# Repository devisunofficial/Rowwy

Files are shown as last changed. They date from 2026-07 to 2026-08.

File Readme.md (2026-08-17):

# Rowwy
Rowwy is a hand-movement control car which uses Mecanum wheels.

### CAD Model:
It has two seperate bodies.

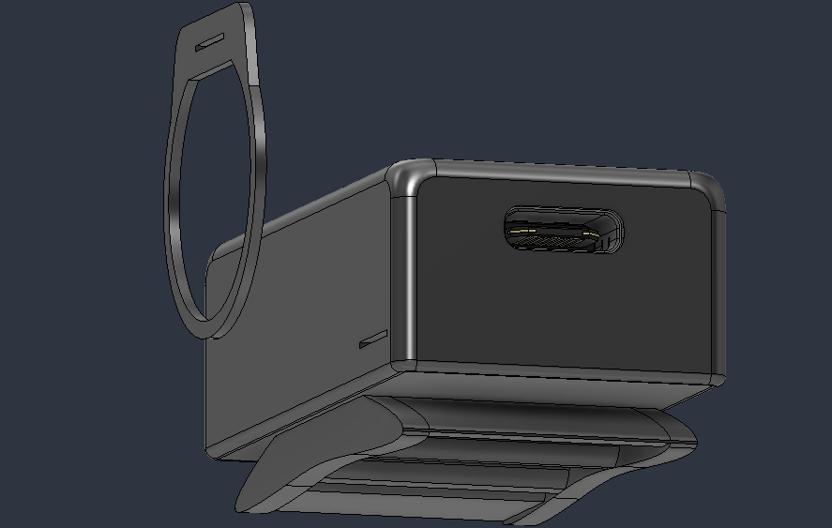
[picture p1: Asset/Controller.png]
Complete Controller
Controller : 

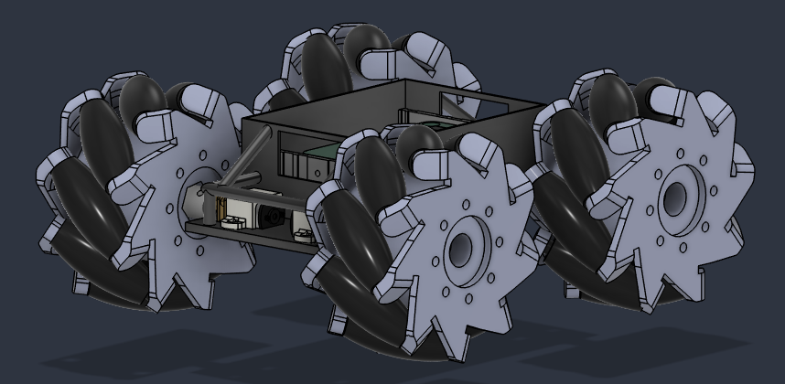
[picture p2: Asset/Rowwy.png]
Complete Rowwy
Rowwy : 

### PCB:
Here's my PCB! It was made in KiCad. 

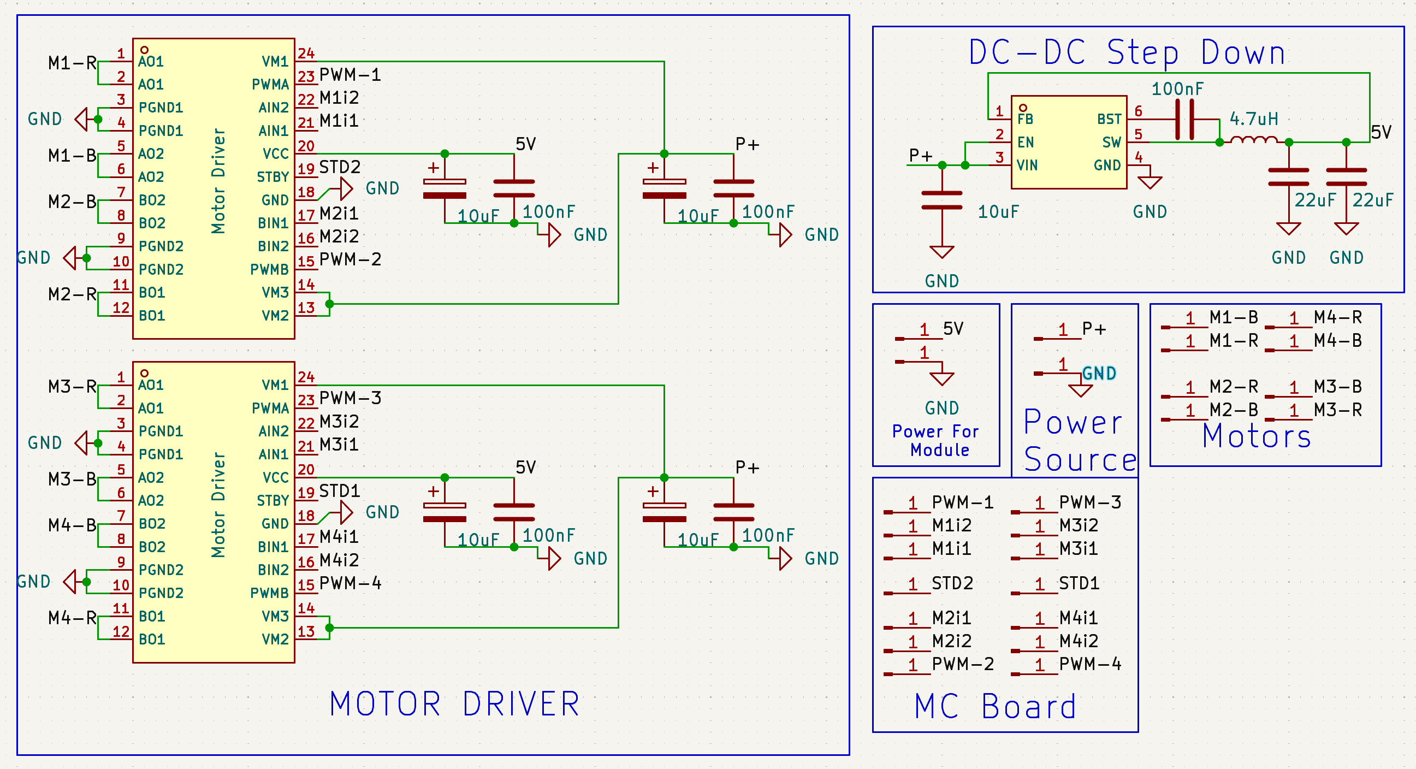
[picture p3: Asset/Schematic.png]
Schematic : 
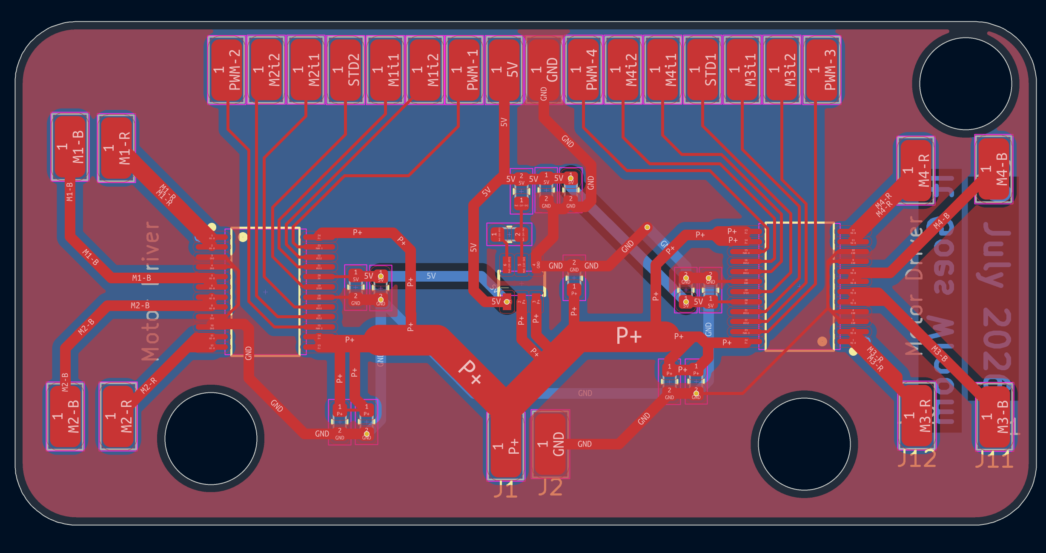
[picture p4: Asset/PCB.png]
PCB Footprint : 

### Firmware Overview:
Current version of Firmware is underdevelopment as it has not be implemeted in real life.
This car and controller uses C++ firmware and Arduino IDE for Flashing.

### Assembly Instructions :
1. Flash Firmware in XIAO ESP32 and Wroom Dev-board
2. Solder Motors, Devboard, Battery of car 
3. Solder Gyro-sensor, Flex-Sensor, Battery of controller
4. Check If Everything Works or not, also update the code depending on soldered pins
5. Glue togetther the controller enclosure and bracelet. Also Glue together battery and all circuits on Rowwy's base plate
6. Screw motor holder to base plate and enjoy the ride.

### BOM Table
|Name|Use|Quantity|Distributer|Total Cost(USD)|Link|
|-----|---|---|---|-----|---|
|18650 battery |Power Source for Car|1|Robu|3|13.2|[Link](https://robu.in/product/samsung-inr18650-25r-2500mah-li-ion-battery/)|
|PCB|Main-Circuit|1|JLCPCB|32|--|
|XIAO ESP32|Controller|1|Robu|7.2|[Link](https://robu.in/product/seeed-studio-xiao-esp32c3-tiny-mcu-board-with-wi-fi-and-ble-battery-charge-supported-power-efficiency-and-rich-interface/)|
|Wroom ESP32 Dev Board|Reciever for Car|1|Robu|7.4|[Link](https://robu.in/product/smartelex-esp-wroom-32-wifi-bluetooth-networking-development-board-1-pcs/)|
|Mecanum Wheels|For Motion|1|Robu|5.3|[Link](https://robu.in/product/80mm-a-mecanum-wheel-compatible-with-6-7mm-coupling-pack-of-4-yellow/)|
|N20 geared Motor|Powering Motion|4|Robu|6.7|[Link](https://robu.in/product/n20-12v-600-rpm-micro-metal-gear-motor/)|
|Battery(1)|For Controller|1|Robu|2|[Link](https://robu.in/product/nova-303040-400mah-3-7v-micro-lipo-battery-pack/)|
|Flex Sensor|Handbreak Functionality|1|Robu|7.3|[Link](https://robu.in/product/flex-sensor-2-2-bend-sensor-hand-gesture-recognition/)|
|MPU6050|Calculating Handmovement|1|Robu|1.5|[Link](https://robu.in/product/mpu6500-gyroscope-accelerometer-digital-motion-processor-dmp-6-axis-motion-sensor-with-i2c-spi-interface/)|
|battery holder|To hold 18650 battery|1|Robu|0.3|[Link](https://robu.in/product/black-plastic-storage-box-case-holder-battery-3-x-18650-cell-box-without-cover/)|
|18650 charger|To charge 18650 battery|1|Amazon|2.1|[Link](https://www.amazon.in/TESTIN-ELECTRONICS-Battery-Charger-Charger-1Slot/dp/B0G4JR7FVW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)|

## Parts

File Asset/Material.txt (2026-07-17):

1. 4 x N20 12V 300RPM Micro Metal Gear Motors with Encoders
2. 4x Mini Mecanum Wheels (48mm Diameter)
3. ESP32-WROOM-32E Microcontroller Module
4. 2x TB6612FNG Dual H-Bridge Motor Driver ICs
5. AP63203 Buck Regulator IC
6. Seeed Studio XIAO ESP32-C3
7. MPU6050 6-DoF Gyroscope & Accelerometer Module
8. Molicel INR18650-P28A 3.6V 2800mAh Lithium-Ion Battery
9. 18650 Polymer Lithium ion Charger Type C to 3S 12.6V 2A Booster Module
10. 3S 12V 25A 18650 Lithium Battery Protection Board

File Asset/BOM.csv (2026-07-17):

Comment | Designator | Footprint
10uF | C1, C5, C7, C9, C11 | C_0603_1608Metric
100nF | C2, C6, C8, C10, C12 | C_0603_1608Metric
22uF | C3, C4 | C_0603_1608Metric
4.7uH | L1 | L_0603_1608Metric
Motor Driver | U1, U3 | C88224_SSOP-24_L8_4-W5_8-P0_65-LS7_8-BL
AP63203WU-7 | U2 | C780769_TSOT-26_L2_9-W1_6-P0_95-LS2_8-BL

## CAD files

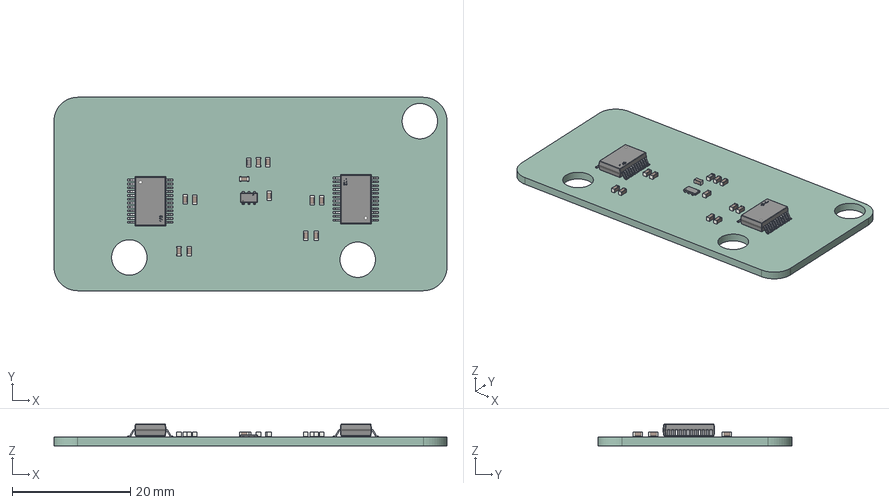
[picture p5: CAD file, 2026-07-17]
Asset/PCB_Rowwy.step
66.6 x 32.8 x 3.70 mm
C_0603_1608Metric x 12
L_0603_1608Metric
SSOP-24_L8.4-W5.3-H2.0-LS7.8-P0.65 x 2
TSOT-26_L2.9-W1.6-P0.95-LS2.8-BL
Rowwy_PCB

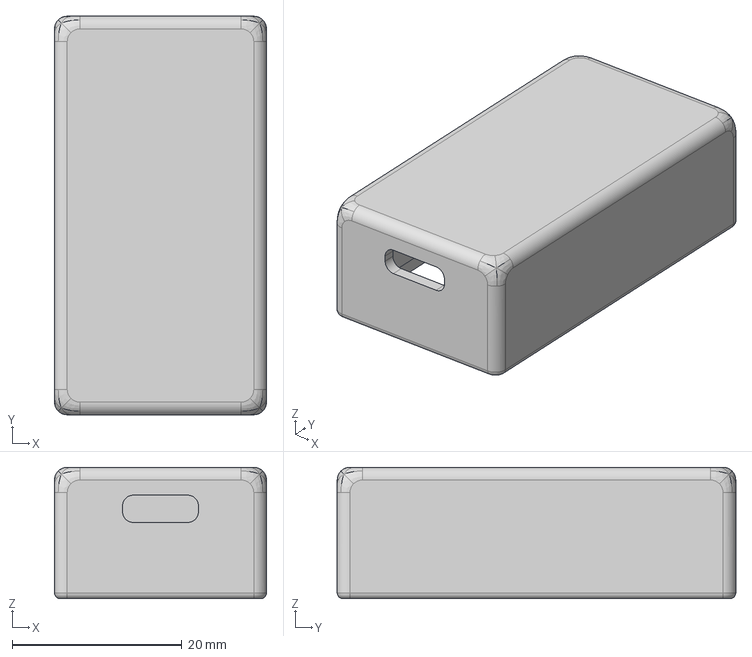
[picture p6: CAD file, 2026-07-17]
CAD/Enclosure.step
25.0 x 47.0 x 15.5 mm

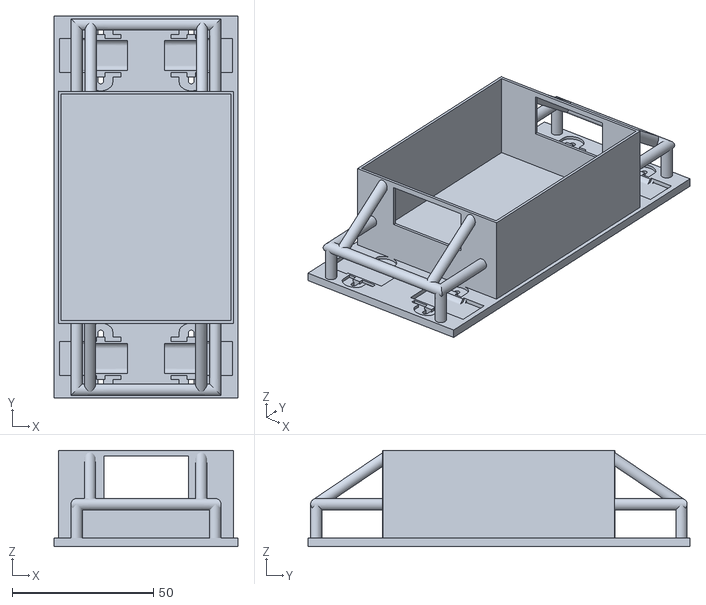
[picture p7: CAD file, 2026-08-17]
Production/CAD Files/Enclosure.stl
65.0 x 135.0 x 34.0

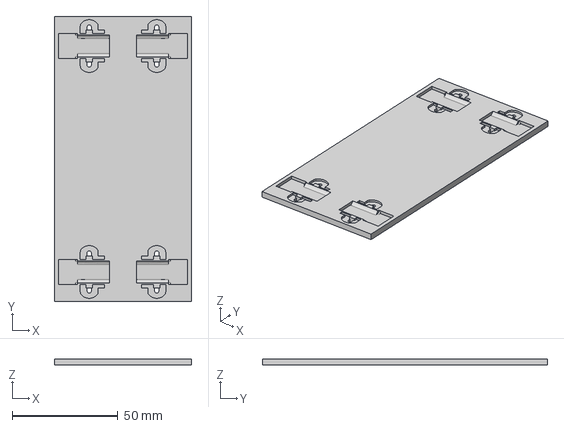
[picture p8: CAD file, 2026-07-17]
CAD/Base.step
65.0 x 135.0 x 3.00 mm

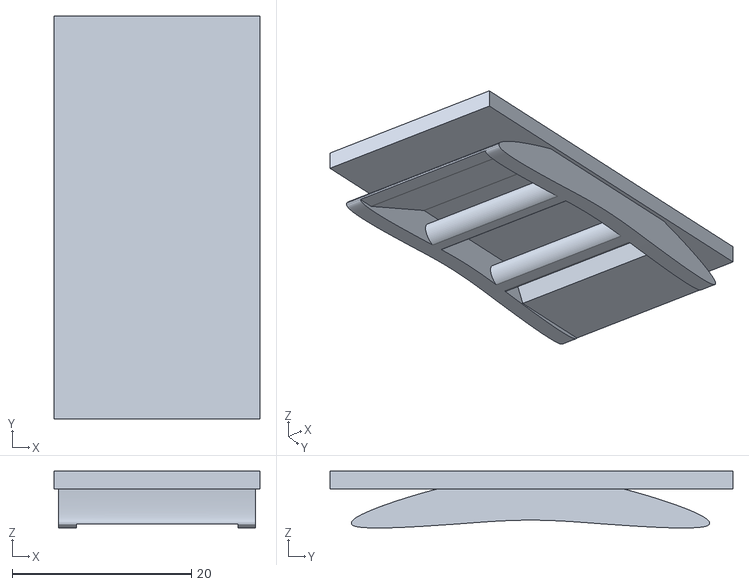
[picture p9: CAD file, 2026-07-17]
Production/CAD Files/Bracelet.stl
23.0 x 45.0 x 6.36

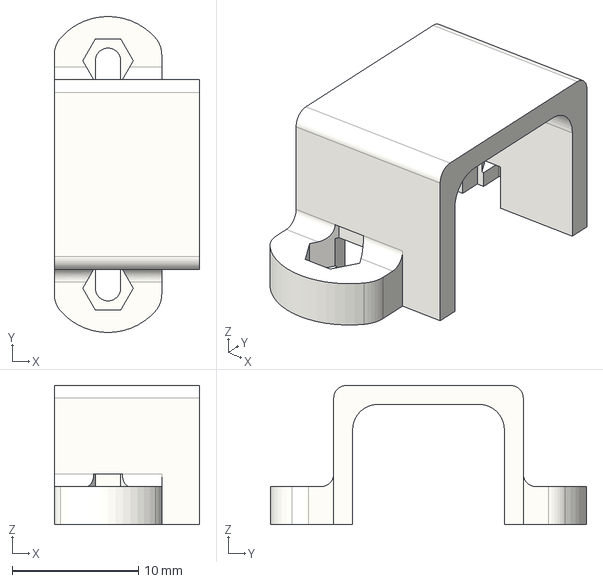
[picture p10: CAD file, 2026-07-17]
CAD/Motor_Bracket.step
11.5 x 25.0 x 11.0 mm

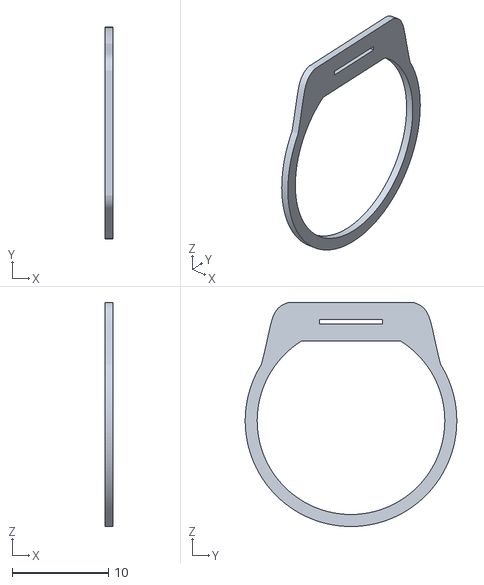
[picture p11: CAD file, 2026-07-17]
Production/CAD Files/Ring.stl
0.8 x 22.0 x 23.3

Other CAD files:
CAD/Bracelet.step
Production/CAD Files/Motor_Bracket.stl
CAD/Ring.step
Production/CAD Files/Base.stl
CAD/Assebly_Rowwy.f3z
CAD/AssemblyController.f3z

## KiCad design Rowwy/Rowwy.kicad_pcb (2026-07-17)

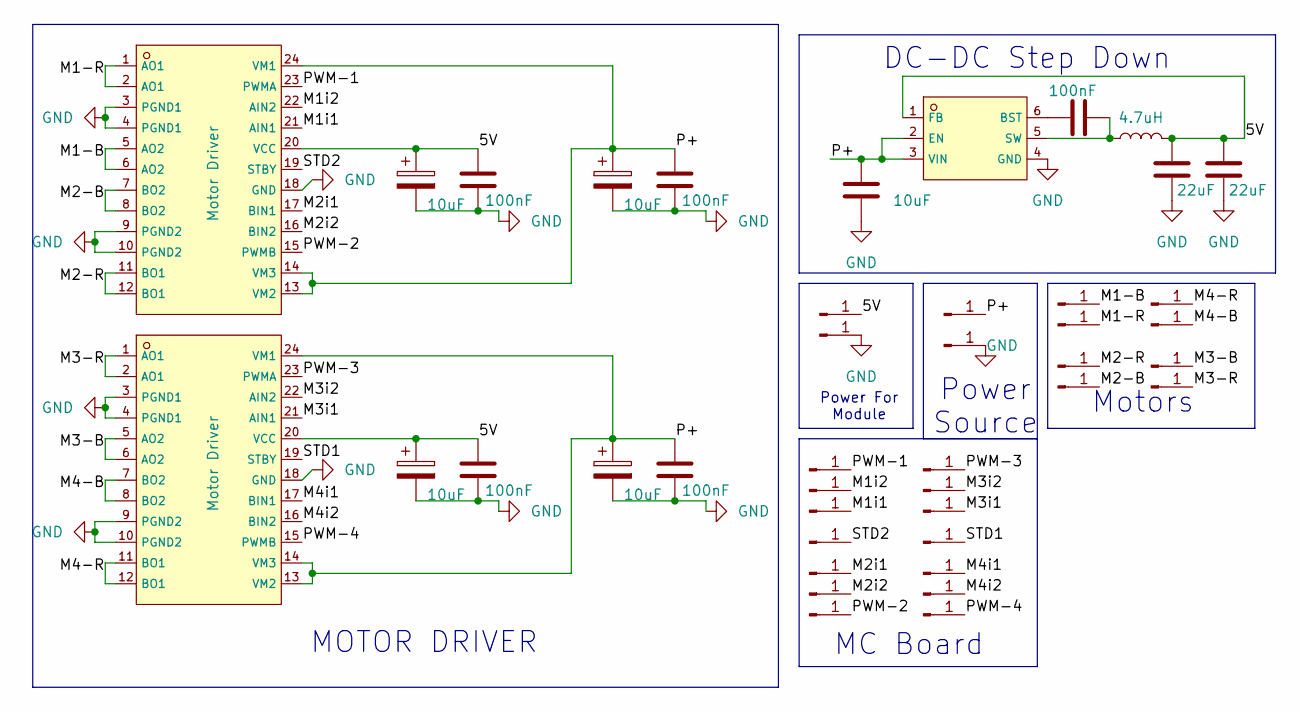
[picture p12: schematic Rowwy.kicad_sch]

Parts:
C1, C5, C7, C9, C11: 10uF; C_0603_1608Metric
C2, C6, C8, C10, C12: 100nF; C_0603_1608Metric
C3, C4: 22uF; C_0603_1608Metric
J1, J2, J3, J4, J5, J6, J7, J8, J9, J10, J11, J12, J13, J14, J15, J16, J17, J18, J19, J20, J21, J22, J23, J24, J25, J26: Conn_01x01_Pin; SolderWirePad_1x01_SMD_2x4mm
L1: 4.7uH; L_0603_1608Metric
U1, U3: Motor Driver; C88224_SSOP-24_L8_4-W5_8-P0_65-LS7_8-BL; LCSC C88224
U2: AP63203WU-7; C780769_TSOT-26_L2_9-W1_6-P0_95-LS2_8-BL; LCSC C780769

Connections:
/5V: C3.1, C4.1, C5.1, C6.1, C9.1, C10.1, J3.1 (Pin_1_1), L1.2, U1.20 (VCC), U2.1 (FB), U3.20 (VCC)
/M1-B: J5.1 (Pin_1_1), U1.5 (AO2), U1.6 (AO2)
/M1-R: J6.1 (Pin_1_1), U1.1 (AO1), U1.2 (AO1)
/M1i1: J15.1 (Pin_1_1), U1.21 (AIN1)
/M1i2: J14.1 (Pin_1_1), U1.22 (AIN2)
/M2-B: J8.1 (Pin_1_1), U1.7 (BO2), U1.8 (BO2)
/M2-R: J7.1 (Pin_1_1), U1.11 (BO1), U1.12 (BO1)
/M2i1: J18.1 (Pin_1_1), U1.17 (BIN1)
/M2i2: J19.1 (Pin_1_1), U1.16 (BIN2)
/M3-B: J11.1 (Pin_1_1), U3.5 (AO2), U3.6 (AO2)
/M3-R: J12.1 (Pin_1_1), U3.1 (AO1), U3.2 (AO1)
/M3i1: J26.1 (Pin_1_1), U3.21 (AIN1)
/M3i2: J25.1 (Pin_1_1), U3.22 (AIN2)
/M4-B: J10.1 (Pin_1_1), U3.7 (BO2), U3.8 (BO2)
/M4-R: J9.1 (Pin_1_1), U3.11 (BO1), U3.12 (BO1)
/M4i1: J21.1 (Pin_1_1), U3.17 (BIN1)
/M4i2: J22.1 (Pin_1_1), U3.16 (BIN2)
/P+: C1.1, C7.1, C8.1, C11.1, C12.1, J1.1 (Pin_1_1), U1.13 (VM2), U1.14 (VM3), U1.24 (VM1), U2.2 (EN), U2.3 (VIN), U3.13 (VM2), U3.14 (VM3), U3.24 (VM1)
/PWM-1: J13.1 (Pin_1_1), U1.23 (PWMA)
/PWM-2: J20.1 (Pin_1_1), U1.15 (PWMB)
/PWM-3: J24.1 (Pin_1_1), U3.23 (PWMA)
/PWM-4: J23.1 (Pin_1_1), U3.15 (PWMB)
/STD1: J17.1 (Pin_1_1), U3.19 (STBY)
/STD2: J16.1 (Pin_1_1), U1.19 (STBY)
GND: C1.2, C3.2, C4.2, C5.2, C6.2, C7.2, C8.2, C9.2, C10.2, C11.2, C12.2, J2.1 (Pin_1_1), J4.1 (Pin_1_1), U1.3 (PGND1), U1.4 (PGND1), U1.9 (PGND2), U1.10 (PGND2), U1.18 (GND), U2.4 (GND), U3.3 (PGND1), U3.4 (PGND1), U3.9 (PGND2), U3.10 (PGND2), U3.18 (GND)
unnamed: C2.1, U2.6 (BST)
unnamed: C2.2, L1.1, U2.5 (SW)

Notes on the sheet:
Motors
DC-DC Step Down
Power Source
MC Board
Power For Module
MOTOR DRIVER

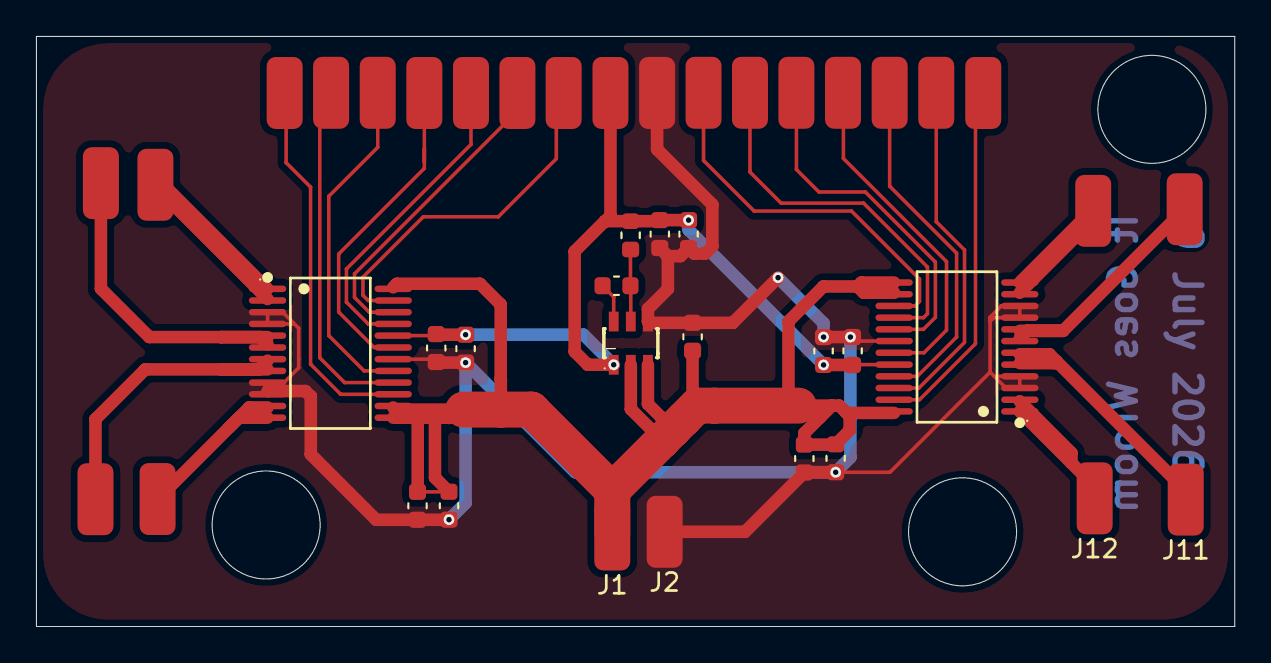
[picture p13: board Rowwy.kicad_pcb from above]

Board: 2 copper layers, 66.6 x 32.8 mm, 42 parts (0 on the bottom side), 27 nets.

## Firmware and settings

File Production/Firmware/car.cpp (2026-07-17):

#include <esp_now.h>
#include <WiFi.h>

#define FL_IN1 2
#define FL_IN2 4
#define FL_PWM 5

#define FR_IN1 12
#define FR_IN2 13
#define FR_PWM 14

// Driver 2: Rear Motors
#define RL_IN1 16
#define RL_IN2 17
#define RL_PWM 18

#define RR_IN1 19
#define RR_IN2 21
#define RR_PWM 22

#define MOTOR_STBY 23

typedef struct struct_message {
    int forward;  // -255 to 255 (Pitch/Tilt from MPU6050)
    int strafe;   // -255 to 255 (Roll/Tilt from MPU6050)
    int turn;     // -255 to 255 (Yaw or dedicated steering input)
    int brake;    // 0 to 1023 (Analog value from linear potentiometer)
} struct_message;

struct_message incomingData;

const int BRAKE_THRESHOLD = 400; 

void moveMotor(int in1_pin, int in2_pin, int pwm_pin, int speed) {
    if (speed > 0) {
        digitalWrite(in1_pin, HIGH);
        digitalWrite(in2_pin, LOW);
        analogWrite(pwm_pin, speed);
    } else if (speed < 0) {
        digitalWrite(in1_pin, LOW);
        digitalWrite(in2_pin, HIGH);
        analogWrite(pwm_pin, abs(speed));
    } else {
        digitalWrite(in1_pin, LOW);
        digitalWrite(in2_pin, LOW);
        analogWrite(pwm_pin, 0);
    }
}

void applyHardBrake() {
    digitalWrite(FL_IN1, HIGH); digitalWrite(FL_IN2, HIGH); analogWrite(FL_PWM, 255);
    digitalWrite(FR_IN1, HIGH); digitalWrite(FR_IN2, HIGH); analogWrite(FR_PWM, 255);
    digitalWrite(RL_IN1, HIGH); digitalWrite(RL_IN2, HIGH); analogWrite(RL_PWM, 255);
    digitalWrite(RR_IN1, HIGH); digitalWrite(RR_IN2, HIGH); analogWrite(RR_PWM, 255);
}

void OnDataRecv(const uint8_t * mac, const uint8_t *incomingDataBuffer, int len) {
    memcpy(&incomingData, incomingDataBuffer, sizeof(incomingData));
    
    if (incomingData.brake > BRAKE_THRESHOLD) {
        applyHardBrake();
        return; 
    }

    int fl_speed = incomingData.forward + incomingData.strafe + incomingData.turn;
    int fr_speed = incomingData.forward - incomingData.strafe - incomingData.turn;
    int rl_speed = incomingData.forward - incomingData.strafe + incomingData.turn;
    int rr_speed = incomingData.forward + incomingData.strafe - incomingData.turn;

    fl_speed = constrain(fl_speed, -255, 255);
    fr_speed = constrain(fr_speed, -255, 255);
    rl_speed = constrain(rl_speed, -255, 255);
    rr_speed = constrain(rr_speed, -255, 255);

    moveMotor(FL_IN1, FL_IN2, FL_PWM, fl_speed);
    moveMotor(FR_IN1, FR_IN2, FR_PWM, fr_speed);
    moveMotor(RL_IN1, RL_IN2, RL_PWM, rl_speed);
    moveMotor(RR_IN1, RR_IN2, RR_PWM, rr_speed);
}

void setup() {
    Serial.begin(115200);

    pinMode(FL_IN1, OUTPUT); pinMode(FL_IN2, OUTPUT); pinMode(FL_PWM, OUTPUT);
    pinMode(FR_IN1, OUTPUT); pinMode(FR_IN2, OUTPUT); pinMode(FR_PWM, OUTPUT);
    pinMode(RL_IN1, OUTPUT); pinMode(RL_IN2, OUTPUT); pinMode(RL_PWM, OUTPUT);
    pinMode(RR_IN1, OUTPUT); pinMode(RR_IN2, OUTPUT); pinMode(RR_PWM, OUTPUT);
    pinMode(MOTOR_STBY, OUTPUT);

    digitalWrite(MOTOR_STBY, HIGH);

    WiFi.mode(WIFI_STA);

    if (esp_now_init() != ESP_OK) {
        Serial.println("Error initializing ESP-NOW");
        return;
    }

    esp_now_register_recv_cb(esp_now_recv_cb_t(OnDataRecv));
    
    Serial.println("Receiver Ready. Waiting for ESP-NOW data...");
}

void loop() {
}

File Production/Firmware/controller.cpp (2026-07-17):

#include <esp_now.h>
#include <WiFi.h>
#include <Wire.h>
#include <Adafruit_MPU6050.h>
#include <Adafruit_Sensor.h>

#define POT_PIN A0        
#define TOUCH_PIN D1      
uint8_t receiverMacAddress[] = {0x00, 0x00, 0x00, 0x00, 0x00, 0x00};

typedef struct struct_message {
    int forward;  
    int strafe;  
    int turn;    
    int brake;  
} struct_message;

struct_message myData;
esp_now_peer_info_t peerInfo;
Adafruit_MPU6050 mpu;

int sensitivityLevel = 1;
bool lastTouchState = LOW;
unsigned long lastDebounceTime = 0;
const unsigned long DEBOUNCE_DELAY = 250;

const int DEADZONE_BUFFER = 30; 

void setup() {
    Serial.begin(115200);

    pinMode(TOUCH_PIN, INPUT);
    analogReadResolution(12);

    Wire.begin();     if (!mpu.begin()) {
        Serial.println("Failed to find MPU6050 chip");
        while (1) { delay(10); }
    }
    
    mpu.setAccelerometerRange(MPU6050_RANGE_8_G);
    mpu.setGyroRange(MPU6050_RANGE_500_DEG);
    mpu.setFilterBandwidth(MPU6050_BAND_21_HZ);

    WiFi.mode(WIFI_STA);

    if (esp_now_init() != ESP_OK) {
        Serial.println("Error initializing ESP-NOW");
        return;
    }

    memcpy(peerInfo.peer_addr, receiverMacAddress, 6);
    peerInfo.channel = 0;  
    peerInfo.encrypt = false;
    
    if (esp_now_add_peer(&peerInfo) != ESP_OK) {
        Serial.println("Failed to add peer");
        return;
    }
}

void loop() {
    bool currentTouchState = digitalRead(TOUCH_PIN);
    if (currentTouchState == HIGH && lastTouchState == LOW && (millis() - lastDebounceTime) > DEBOUNCE_DELAY) {
        sensitivityLevel = (sensitivityLevel + 1) % 3;
        lastDebounceTime = millis();
        Serial.print("Sensitivity Changed to Level: ");
        Serial.println(sensitivityLevel);
    }
    lastTouchState = currentTouchState;

    float maxTiltAngle = 45.0; 
    if (sensitivityLevel == 1) maxTiltAngle = 30.0; 
    if (sensitivityLevel == 2) maxTiltAngle = 15.0; 

    sensors_event_t a, g, temp;
    mpu.getEvent(&a, &g, &temp);

    float pitch = atan2(-a.x, sqrt(a.y * a.y + a.z * a.z)) * 180.0 / M_PI;
    float roll  = atan2(a.y, a.z) * 180.0 / M_PI;

    int rawForward = map(constrain(pitch, -maxTiltAngle, maxTiltAngle), -maxTiltAngle, maxTiltAngle, -255, 255);
    int rawStrafe  = map(constrain(roll, -maxTiltAngle, maxTiltAngle), -maxTiltAngle, maxTiltAngle, -255, 255);
    
    int rawTurn = map(constrain(g.gyro.z, -2.0, 2.0), -2.0, 2.0, -255, 255);

    myData.forward = (abs(rawForward) < DEADZONE_BUFFER) ? 0 : rawForward;
    myData.strafe  = (abs(rawStrafe) < DEADZONE_BUFFER)  ? 0 : rawStrafe;
    myData.turn    = (abs(rawTurn) < DEADZONE_BUFFER)    ? 0 : rawTurn;

    int potVal = analogRead(POT_PIN);
    myData.brake = map(potVal, 0, 4095, 0, 1023);

    esp_err_t result = esp_now_send(receiverMacAddress, (uint8_t *) &myData, sizeof(myData));
    
    delay(20); 
}

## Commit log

2026-07-17 Simplify CAD model section in Readme.md
    Consolidate CAD model descriptions into a single line.
2026-08-17 Updated BOM.csv and BOM in readme.md
    [Assebly_Rowwy.f3z, BOM.csv, Enclosure.stl]
